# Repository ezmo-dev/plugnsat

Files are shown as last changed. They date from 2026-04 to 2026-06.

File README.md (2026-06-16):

# PlugNSat

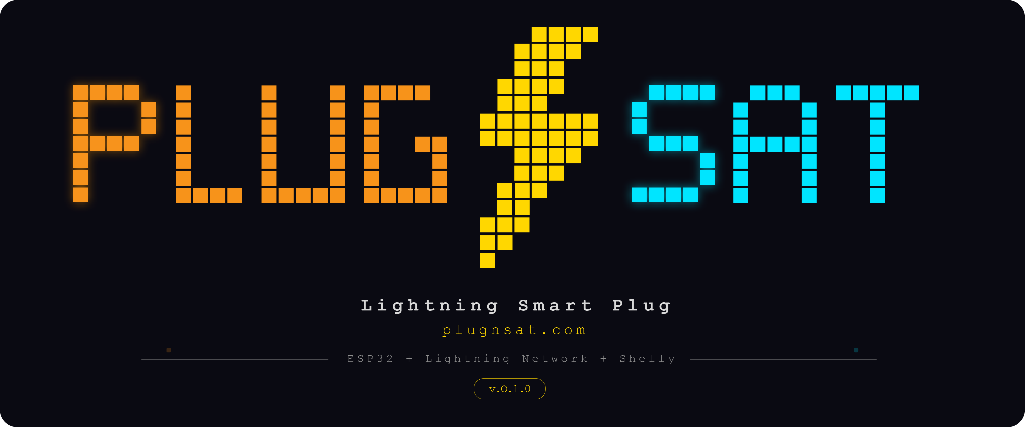
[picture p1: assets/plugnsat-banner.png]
cover

An open-source Lightning Smart Plug Controller. Turn any device into a Bitcoin-powered machine!

PlugNSat is an ESP32-based controller that displays a Lightning invoice QR code on screen.
When a customer pays, it triggers a CE-certified Shelly smart plug to power on any connected device (5V, 12V, 220V...) for a configurable duration and price.
Supports BTCPay Server (self-hosted) and Blink (hosted wallet) as Lightning backends.

Connect to WiFi, set your price in sats, and go!
No modification to the target device needed.

Built for Bitcoin hubs, conferences, stores, coworking spaces, companies, meetups, events, and more.

## How it works
```
[QR on screen] --> [Customer scans] --> [Pays Lightning] --> [Shelly ON] --> [New QR]
     ^                                                                          |
     |__________________________________________________________________________|
                              (automatic loop)
```

The QR code is always displayed. No button press needed to start a payment.
QR auto-refreshes every 4m45s before the 5-minute invoice expiry.

## Hardware

| Part | Price | Link |
|---|---|---|
| LilyGO T-Display S3 | ~20 EUR | [amazon.fr](https://www.amazon.fr/dp/B0BX8Q2MJP) |
| Shelly Plug S Gen3 | ~26 EUR | [amazon.fr](https://www.amazon.fr/dp/B0DJFQXTY2) |

## Arduino IDE Setup

1. Install [Arduino IDE 2.x](https://www.arduino.cc/en/software)
2. Add ESP32 boards: File > Preferences > Board Manager URLs:
   `https://raw.githubusercontent.com/espressif/arduino-esp32/gh-pages/package_esp32_index.json`
3. Install "esp32" in Board Manager
4. Board: ESP32S3 Dev Module
5. USB CDC On Boot: Enabled
6. Flash Size: 16MB
7. Partition Scheme: Minimal SPIFFS (1.9MB APP with OTA/128KB SPIFFS)

### Libraries (Sketch > Include Library > Manage Libraries)

- **TFT_eSPI** by Bodmer (+ configure User_Setup_Select.h for T-Display S3)
  - Line 27: Comment `#include <User_Setup.h>` (add `//` in front)
  - Line 133: Uncomment `#include <User_Setups/Setup206_LilyGo_T_Display_S3.h>` (remove `//`)
- **ArduinoJson** by Benoit Blanchon
- **QRCode** by Richard Moore

## Setup

### 1. Prepare the Shelly Plug

1. Download the **Shelly app** ([iOS](https://apps.apple.com/app/shelly-cloud/id1147164547) / [Android](https://play.google.com/store/apps/details?id=cloud.shelly.smartcontrol))
2. Plug the Shelly into a wall outlet
3. Open the app and follow the instructions to add the device to your WiFi network
4. Once connected, open the plug settings and, under Input/Output settings, configure the Shelly to turn OFF when it has power (so the connected device stays off until a payment is received)

> The Shelly must be on the same WiFi network that PlugNSat will connect to.

### 2. Flash the firmware (DIY only)

> Skip this step if you bought a pre-assembled PlugNSat.

1. Connect the LilyGO T-Display S3 to your computer via USB-C
2. Open Arduino IDE, select the board and settings (see [Arduino IDE Setup](#arduino-ide-setup) above)
3. Upload the firmware
4. The device shows the "PlugNSat Setup" screen

### 3. Configure PlugNSat

1. Power on the PlugNSat via USB-C
2. On your phone, connect to WiFi: `PlugNSat-Setup` (password: `plugnsat21`)
3. Open `http://192.168.4.1` in your browser
4. Enter your WiFi credentials (same network as the Shelly)
5. Choose your Lightning backend (BTCPay Server or Blink) and fill in the corresponding credentials
6. Click **Scan network** to auto-discover your Shelly, or type its hostname/IP manually
7. Set your price in sats, activation duration in seconds, optionally a 4-digit PIN to protect these settings on the device, and optionally a portal password to protect this web page (username: admin)
8. Click **Save and restart**
9. The device connects to WiFi and the QR code appears. You're live!

## Buttons

| Button | Short press | Long press (3s) |
|---|---|---|
| BTN1 (left) | Settings menu / Navigate | Enter AP setup mode |
| BTN2 (right) | Force QR refresh / Confirm | - |

## Firmware Updates

PlugNSat supports over-the-air updates. Two ways to update:

- **Auto-update on boot** (opt-in): enable it in the web portal and the device checks GitHub Releases at every boot, then installs new versions automatically.
- **One-click update**: open `http://plugnsat.local`, click **Check for updates** in the Firmware update section, then **Install update** if a new version is available.

All firmware is RSA-signed. The device verifies the signature before flashing and refuses unsigned or tampered files. If an update fails to boot, the device automatically rolls back to the previous version within 60 seconds.

### Settings menu

Press BTN1 from the QR screen to open the Settings menu.

| Option | Description |
|---|---|
| Device Info | WiFi, IP, RSSI, Shelly host, price, duration, payments, uptime |
| Brightness | Adjust screen brightness (BTN1 decreases, BTN2 increases) |
| Price | Change price in sats (BTN1 decreases, BTN2 increases) |
| Duration | Change activation duration in seconds (BTN1 decreases, BTN2 increases) |
| Turn OFF | Battery model only. Puts the device into deep sleep. Wake with BTN1 or by connecting USB power. |

Price and Duration can be protected with a 4-digit PIN, configurable in the web portal. If a PIN is set, it must be entered before accessing these settings.

Navigation: BTN1 moves the cursor, BTN2 selects. All screens return to the QR code automatically after 6 seconds of inactivity. Changes to Brightness, Price, and Duration are saved automatically on exit. On the Device Info screen, press any button to return to the QR code.

## Files
```
plugnsat.ino   Main sketch, state machine, WiFi, buttons
config.h       Constants, colors, config struct
display.h      All screen rendering (splash, QR, paid, error, info, settings, brightness, AP)
btcpay.h       BTCPay Server API (create invoice, check status)
blink.h        Blink wallet GraphQL API (create invoice, check status)
backend.h      Lightning backend abstraction layer (BTCPay Server, Blink)
shelly.h       Shelly local HTTP API (switch on/off, status)
webportal.h    Web config page (HTML/CSS/JS served by ESP32)
qrcode.h       QR code generation library header (by Richard Moore)
qrcode.c       QR code generation library source
ota.h          OTA system: rollback guard, RSA signature verification, GitHub update check and download
```

All files go in the same folder. Arduino IDE compiles them together.

## Edge Cases Handled

- WiFi disconnects > auto reconnect, QR regenerated
- Backend unreachable > retry 3x, then error screen, auto-retry 10s
- Invoice expires > new QR generated silently
- Shelly offline during payment > "Shelly not found" warning screen > auto-retry every 10s > when Shelly comes back online: paid screen with full countdown + activation command sent with full duration > payment is confirmed regardless of Shelly status
- Shelly hostname (mDNS .local) supported to avoid DHCP IP changes
- "Scan network" button in the web portal auto-discovers Shelly devices via mDNS (no IP needed)
- 60+ consecutive poll errors (5 min) > ESP32 restarts itself
- Long press BTN1 from any screen > AP setup mode

## License

MIT © 2026 - [ezmo-dev](https://github.com/ezmo-dev) (PlugNSat)

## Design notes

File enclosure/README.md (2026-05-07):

# Enclosure

3D printed case for the LilyGO T-Display S3 (version without header pins).

## Current model

- **Type**: USB-powered, no battery, no mount
- **Fits**: LilyGO T-Display S3 (170x20x8mm PCB)
- **Buttons**: accessible from outside
- **USB-C**: open slot at the bottom

## Print settings

- **Filament**: PLA or PETG
- **Layer height**: 0.2mm
- **Infill**: 15%
- **Supports**: no
- **Estimated time**: ~3h05

## Files

| File | Description |
|---|---|
| `stl/plugnsat-case_top.stl` | Top shell |
| `stl/plugnsat-case_bottom.stl` | Bottom shell |

## Planned variants

- [ ] Integrated LiPo battery version
- [ ] Wall mount
- [ ] Desk stand (angled for QR scanning)

## Notes

STL files are print-ready, no scaling needed.
Printing on a Dagoma DiscoEasy200

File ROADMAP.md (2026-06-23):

### v0.1 — Released
- [x] Basic prototype: LNURL QR, BTCPay polling, Shelly activation
- [x] Web portal configuration
- [x] Auto QR refresh before invoice expiry
- [x] Simulate payment button for testing
- [x] mDNS autodiscovery for Shelly devices
- [x] Splash screen with logo and branding
- [x] Color theme and screen brightness adjustments
- [x] Adjust price and duration from device buttons (PIN-protected)
- [x] First 3D print case
- [x] Web portal UI redesign (light theme, step-based layout)
- [x] UI polish: paid screen, error screen, info screen, settings screen
- [x] Better error messages and info indicators on all screens
- [x] Info tooltips on web portal fields
- [x] QR display modes: Show name/price toggles on QR screen (configurable via web portal)
- [x] First test video
- [x] Documentation structure: create outline with all major sections
- [x] README v1 on GitHub
- [x] Full code cleanup before moving forward

### v0.2 — Blink integration, OTA, and enclosures (current)
- [x] Blink wallet API integration
- [x] Backend choice on web portal: BTCPay or Blink
- [x] Web portal adapts fields based on backend choice
- [x] Update info indicators on web portal for both backends
- [x] Fix: infinite paid/activation loop after payment timer expires
- [x] Add descriptive memo to Blink invoices (device name + amount)
- [x] Merge Lightning Backend selector and credentials into a single configuration step
- [x] Add collapsible accordion sections to configuration page with chevron, summary line, and state persistence
- [x] Rewrite all configuration page tooltips for clarity
- [x] OTA Phase 1: partition scheme with two OTA slots, flash and reboot on the other slot, automatic rollback
- [x] OTA Phase 2: local Web OTA, upload a .bin from the portal (protected by portal password)
- [x] OTA Phase 3: firmware signing, RSA key pair, signature verified before any flash
- [x] OTA Phase 4: version check via GitHub Releases API, TLS validation with embedded root CA
- [x] OTA Phase 5: download and flash signed .bin from GitHub, opt-in via portal button
- [x] OTA Phase 6: controlled deployment, release delay and staged rollout, optional auto-update on boot
- [x] Research and select the right LiPo battery model (capacity, connector, dimensions for enclosure)
- [x] "Check for updates" button in web portal
- [x] Auto-update option on boot
- [x] Battery-powered prototype (LiPo integration with T-Display S3)
  - [x] GPIO15 power-enable for battery operation (screen on without USB)
  - [x] VBAT reading on GPIO4 with onboard divider, factory eFuse + 1.017 calibration
  - [x] Battery model flag (isBattery) in config + web portal toggle, persisted
- [x] Power management: sleep mode, low battery indicator on screen
  - [x] Manual Turn OFF in settings menu (deep sleep, wake on BTN_1 or USB)
  - [x] Software low-voltage cutoff at 3100mV (confirmed over consecutive reads)
  - [x] Low battery warning: blinking crossed-out icon, bottom-right of main screen
  - [x] RTC pull-up on wake pin to prevent immediate wake
- [x] Battery level indicator on screen and web portal
  - [x] Device Info: battery icon, voltage (X.XX/4.20V), percentage (LiPo curve)
  - [x] Charging icon when voltage trend is rising
- [x] Battery UI polish: refine design of all battery-related screen elements
- [ ] Enclosure prototypes (USB and battery): desk stand, magnetic mount, wall mount
- [ ] Test prints for each enclosure
- [x] General V0.2 audit: review all new features for correctness and consistency
- [x] Security audit: review all new features (portal auth, XSS, input validation)
- [ ] Finish documentation: User Manual, Web Portal Reference, Troubleshooting (Quick Start done; needed for landing page)

### v0.3 — Landing page and USB beta testing
- [ ] Finalize USB and battery enclosures and publish STL files on GitHub
- [ ] UI improvements on screen: price and device name alongside QR, WiFi signal indicator, battery level
- [ ] Full design coherence review: screens, web portal, enclosures, docs
- [ ] Landing page v1 on plugnsat.com (USB + battery)
- [ ] Product photos for landing page: device, enclosures, screens, setup flow
- [ ] Product video for landing page
- [ ] Quick-start guide (printed in box)
- [ ] Troubleshooting page
- [ ] Beta testing USB and battery models: send units to trusted people
- [ ] Collect feedback on setup, documentation, enclosure, daily use
- [ ] Code cleanup

### v0.4 — Product finalization and packaging
- [ ] Fix issues reported by beta testers
- [ ] Finalize battery enclosures: desk stand, magnetic mount, wall mount
- [ ] Packaging design: box, insert, printed quick-start guide, sticker
- [ ] Update documentation and landing page with beta feedback
- [ ] Product photos and video for USB and battery models

### v0.5 — Pre-launch and production ready
- [ ] Market study: target segments, pricing per model, competitors
- [ ] Pricing strategy finalized: USB, battery (kit vs pre-assembled)
- [ ] Sales channels defined: plugnsat.com, conferences, resellers, partner shops
- [ ] Landing page updated with final pricing and buy CTAs
- [ ] Collect testimonials from beta testers for landing page
- [ ] Full documentation site (docs.plugnsat.com)
- [ ] CE compliance documentation package for resellers
- [ ] Firmware changelog page on plugnsat.com
- [ ] Packaging production ready
- [ ] Stable, battle-tested product (USB and battery shipping reliably)

### v0.6 — Community sharing
- [ ] Share on Bitcoin communities: Twitter, Nostr, Telegram groups, forums
- [ ] Share on Reddit: r/bitcoin, r/lightningnetwork, r/esp32
- [ ] Present at local meetups
- [ ] Post on Plan B Network, Stacker News
- [ ] Collect feedback, testimonials, and early interest

### v1.0 — Sales and distribution
- [ ] Public sales on plugnsat.com: USB and battery (kit and pre-assembled)
- [ ] Battery model to resellers (desk stand, magnetic mount, wall mount)
- [ ] Contact Bitcoin shops and resellers
- [ ] Send demo units to potential partners
- [ ] Present at Bitcoin conferences
- [ ] Explore distribution partnerships (hubs, coworking chains, event organizers)

---
 
## Post-v1.0 (conditional on sales traction)
 
### NFC model
- [ ] NFC module integration (PN532 or similar)
- [ ] Tap-to-pay flow: NFC reads LNURL, wallet opens, pay
- [ ] NFC + QR dual mode on screen
- [ ] Enclosure prototypes for NFC model (antenna positioning)
- [ ] Finalize NFC enclosures and publish STL files
- [ ] Beta testing NFC model with trusted people
- [ ] Update documentation: NFC setup guide
- [ ] Update landing page with NFC model
- [ ] Product photos and video for NFC model
### Multi-device support
- [ ] New web portal section: device manager with "+" button to add PlugNSat units
- [ ] Per-device configuration: name, price, duration, Shelly host
- [ ] Device list view with status (online/offline, last payment, uptime)
- [ ] Edit and remove devices from the portal
- [ ] Multi-device firmware support (one BTCPay store, multiple devices)
- [ ] Multi-device documentation
- [ ] Beta testing multi-device with hub managers and coworking spaces
### Future ideas
- [ ] Sub-domain dashboard per client (client.plugnsat.com)
- [ ] Usage statistics and payment history
- [ ] Multiple Shelly devices per controller
- [ ] Multi-language support on web portal and screen
- [ ] Fiat price display (sats + EUR/USD equivalent)
- [ ] Receipt/proof of payment via email or NFC
- [ ] Referral program for existing buyers
- [ ] White-label option (custom branding per client)
- [ ] Optional OLED/AMOLED screen version for outdoor use
- [ ] Wall-flush Shelly install behind drywall
### Product lineup
- **PlugNSat USB** - Base model (USB-C powered, kit or pre-assembled) — plugnsat.com only
- **PlugNSat Battery** - Portable model (LiPo rechargeable, kit or pre-assembled) — plugnsat.com and resellers
- **PlugNSat NFC** - Premium model (QR + tap-to-pay), post-v1.0 if sales follow
- **Enclosures** - Desk stand, magnetic mount, wall mount
- **Accessories** - Extra Shelly Plug S Gen3, replacement USB-C cables, sticker pack
- **Free resources** - STL files on GitHub, online documentation, open-source firmware

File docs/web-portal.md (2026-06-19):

# Web Portal Reference

The web portal is the configuration interface served by the PlugNSat itself. It runs directly on the ESP32 and is accessible from any browser on the same network.

## How to access the web portal

There are two ways to reach the web portal depending on the device's current state:

**During first setup (AP mode):**

1. Connect your phone to WiFi: `PlugNSat-Setup` (password: `plugnsat21`)
2. Open `http://192.168.4.1` in your browser

**After setup (normal mode):**

1. Connect to the same WiFi network as the PlugNSat
2. Find the device's IP address (shown on the Device Info screen: BTN1 from QR > Device Info)
3. Open `http://<device-ip>` in your browser, or use `http://plugnsat.local` (mDNS)

> The web portal works on any modern browser: Safari, Chrome, Firefox, on both mobile and desktop. No app needed.

> In AP mode the portal is never password-protected, so you can never lock yourself out during setup. A Web Access Password (see Step 5) only applies in normal mode on your WiFi.

> **AP mode is a configuration and recovery mode, not an operating mode.** Anyone who can connect to the `PlugNSat-Setup` network (password: `plugnsat21`) has unrestricted access to the portal. Once you have entered your WiFi credentials and pressed Save, the device switches to normal mode where the Web Access Password is enforced. Do not leave the device in AP mode during normal operation.

---

## Configuration fields

The portal is organized in 5 steps. All fields are saved at once when you press **Save and restart**. Each step can be collapsed or expanded by tapping its title; the collapsed state is remembered in your browser.

### Step 1: WiFi

| Field | Description | Example |
|---|---|---|
| **SSID** | Your WiFi network name (2.4 GHz). The Shelly must be on the same network. | `MyHomeWiFi` |
| **Password** | Your WiFi password. | `********` |

> The Shelly Plug S Gen3 only supports 2.4 GHz networks. If your router broadcasts both 2.4 and 5 GHz under the same name, you may need to separate them or force the 2.4 GHz band.

> For security, saved passwords are never sent back to the browser. Existing values appear as `********`. Leave them untouched to keep the current password, or type a new one to replace it.

### Step 2: Lightning Backend

PlugNSat supports two Lightning backends. Select one from the **Backend** dropdown; the form shows only the fields for the selected backend.

| Backend | When to use |
|---|---|
| **BTCPay Server** | You run your own server. Full control, no middleman. |
| **Blink** | A ready-to-use wallet, no server needed. Sign up at `blink.sv`. |

#### BTCPay Server fields

| Field | Description | Example |
|---|---|---|
| **Server URL** | The full URL of your BTCPay Server instance. No trailing slash. | `https://btcpay.mydomain.com` |
| **API Key** | Your BTCPay Greenfield API key. Must have the correct permissions (see below). | `a1b2c3d4e5...` |
| **Store ID** | Your BTCPay Store ID. Found in Settings > General or in the URL. | `8HRcCq...HwPs` |

##### Required API key permissions

The API key must have exactly these three permissions enabled:

| Permission | Internal name | Why it's needed |
|---|---|---|
| Create invoices | `cancreateinvoice` | To generate Lightning invoices when a customer scans the QR |
| View invoices | `canviewinvoices` | To check if an invoice has been paid (polling) |
| Use Lightning node | `canuselightningnode` | To retrieve the LNURL from the invoice's payment methods |

To create a key: BTCPay Server > Account > Manage Account > API Keys > Generate Key > check the three permissions > Generate > copy immediately.

##### How it works technically

When a QR code needs to be generated, the PlugNSat:

1. Creates an invoice via `POST /api/v1/stores/{storeId}/invoices` with amount in BTC, payment methods `BTC-LN` and `BTC-LNURL`, and a 5-minute expiry
2. Fetches the payment methods via `GET /api/v1/stores/{storeId}/invoices/{id}/payment-methods`
3. Extracts the LNURL from the `BTC-LNURL` payment method's `paymentLink` field
4. Displays the LNURL as a QR code (much shorter than a BOLT11 invoice, which makes the QR simpler and easier to scan on the small LCD)
5. Polls the invoice status every 5 seconds via `GET /api/v1/stores/{storeId}/invoices/{id}` and checks for `Settled` or `Processing`

#### Blink fields

| Field | Description | Example |
|---|---|---|
| **API Key** | Your Blink API key. Generate one at `dashboard.blink.sv` under API Keys. | `blink_...` |
| **BTC Wallet ID** | Which wallet receives the sats. Found at `dashboard.blink.sv`. | `f79a...` |

> Blink uses the GraphQL API at `https://api.blink.sv/graphql` (fixed endpoint, no server URL to enter). It returns a BOLT11 invoice rather than an LNURL, so the QR code is longer than with BTCPay but still scannable easily.

### Step 3: Shelly Plug

| Field | Description | Example |
|---|---|---|
| **Shelly hostname or IP** | The address of your Shelly on the local network. Can be an IP or an mDNS hostname. | `shellyplugsg3-9070694c2cd4.local` |

> Make sure the Shelly is plugged in, on the same WiFi, and set to **Off** as its default power-on state.

#### Scan network

Click **Scan network** to auto-discover Shelly devices on the local network via mDNS. The PlugNSat queries `_http._tcp` services and keeps the ones whose hostname starts with `shelly`. Matches appear in a dropdown for easy selection.

<p>
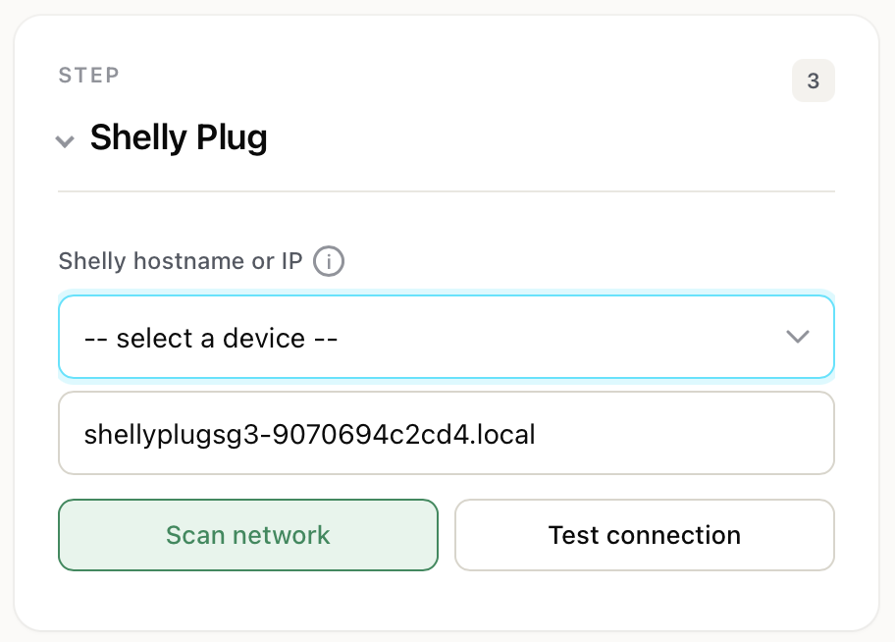
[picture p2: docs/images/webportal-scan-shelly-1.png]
    
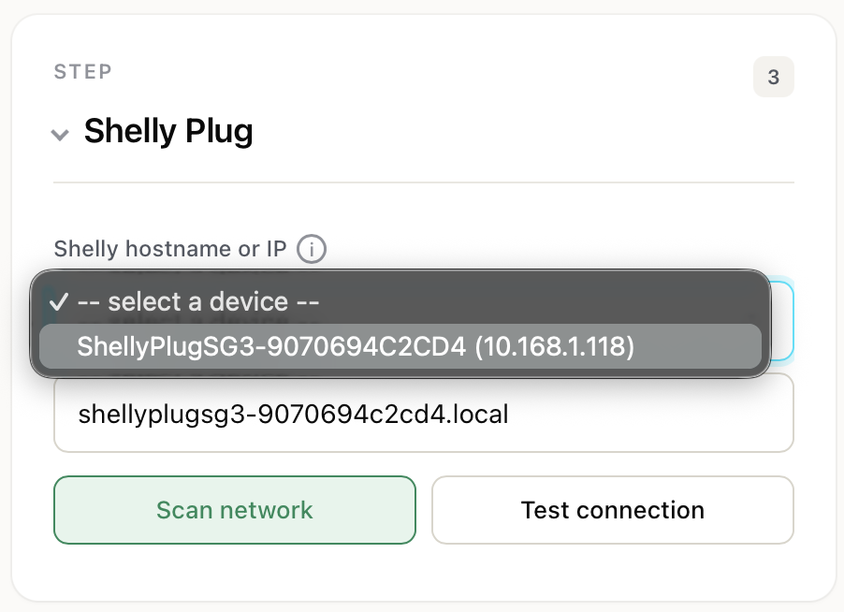
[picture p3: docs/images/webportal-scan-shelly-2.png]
    
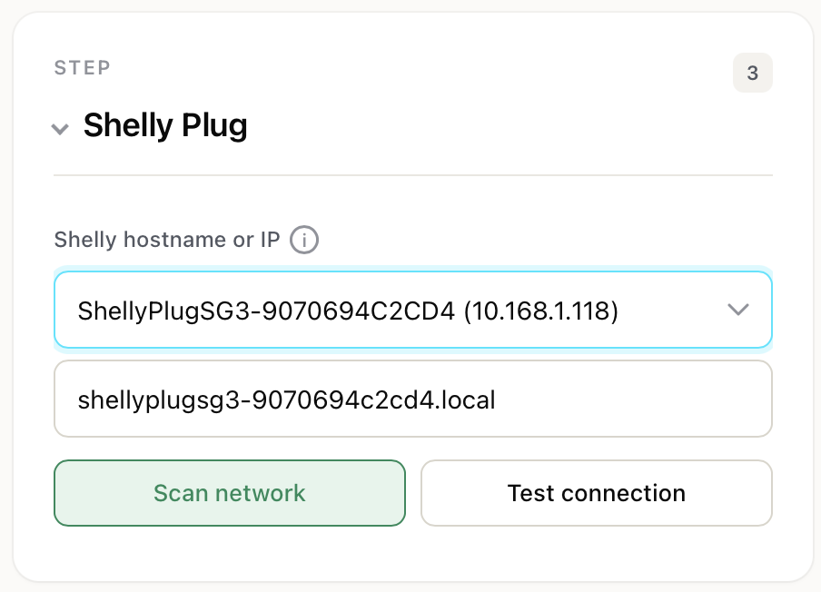
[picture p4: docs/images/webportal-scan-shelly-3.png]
    
<p>

> **Tip:** Use the mDNS hostname (`.local`) instead of the IP address. IP addresses can change if your router assigns a new one via DHCP. The mDNS hostname stays the same.

#### Test connection

Click **Test connection** to verify the PlugNSat can reach the Shelly. It sends an HTTP request to the Shelly's status endpoint (`/rpc/Switch.GetStatus?id=0`). If successful, you see a green confirmation with the current power draw in watts.

<p>
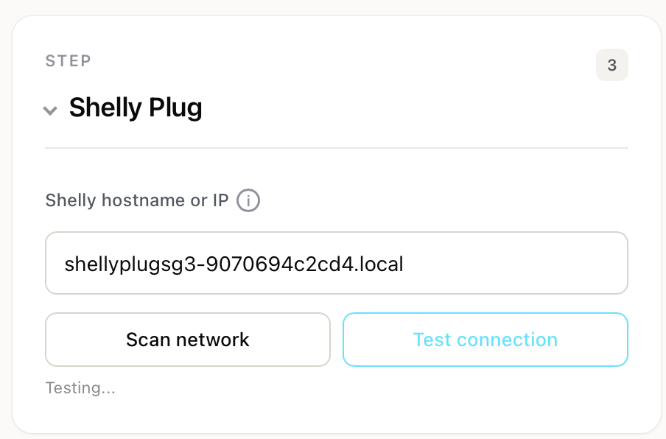
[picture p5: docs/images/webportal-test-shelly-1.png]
    
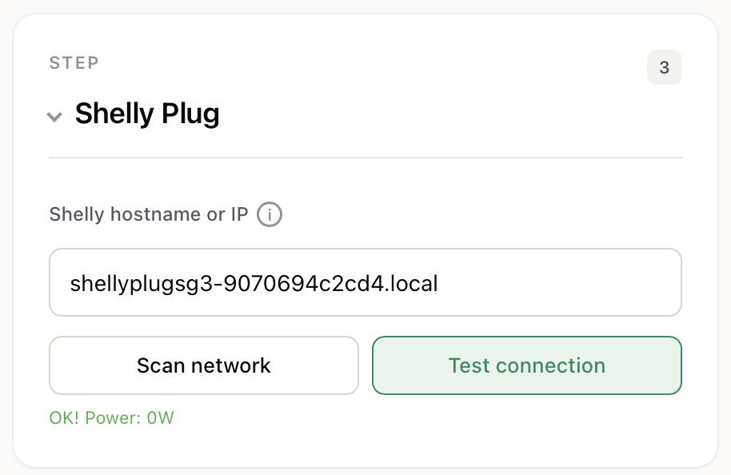
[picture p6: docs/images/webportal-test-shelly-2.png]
    
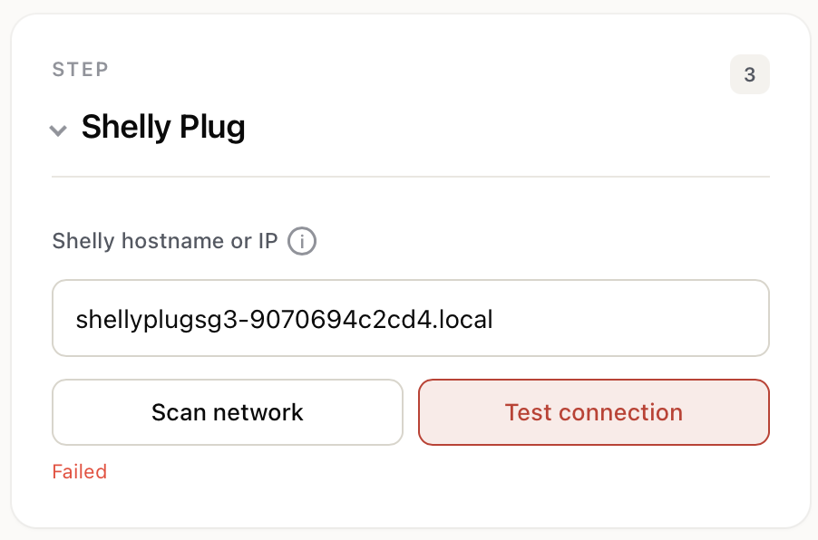
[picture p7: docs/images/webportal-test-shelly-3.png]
    
<p>

#### How the Shelly is controlled

The PlugNSat communicates with the Shelly via local HTTP API (Shelly Gen2+ RPC). No cloud, no internet, no firmware modification.

| Action | Endpoint |
|---|---|
| Turn on (with auto-off timer) | `GET /rpc/switch.set?id=0&on=true&toggle_after={seconds}` |
| Turn off | `GET /rpc/switch.set?id=0&on=false` |
| Check status | `GET /rpc/Switch.GetStatus?id=0` |

The `toggle_after` parameter tells the Shelly to turn itself off after the configured duration. This means even if the PlugNSat loses power or WiFi, the Shelly will still turn off on time.

### Step 4: Device settings

| Field | Description | Default | Range |
|---|---|---|---|
| **Name** | Display name for your PlugNSat. Shown on the info panel next to the QR if enabled. | `PlugNSat` | 1 to 40 characters (max 18 when "Show name" is on) |
| **Show name on QR screen** | Toggle. When on, the name appears next to the QR code. | Off | On/Off |
| **Price (satoshis)** | The amount a customer pays per activation. | `100` | 1 to 1,000,000 sats |
| **Duration (seconds)** | How long the Shelly stays on after payment. | `60` | 1 to 86400 (24h) |
| **Show price on QR screen** | Toggle. When on, the price in sats appears next to the QR code. | Off | On/Off |

> **Name length and QR layout:** If "Show name" is enabled, the QR code shifts to the left to make room for the info panel. Long names (more than 9 characters) wrap to two lines. With display enabled the portal enforces a maximum of 18 characters; with display off the limit is 40.

#### Simulate payment

Below the device fields you will find a **Simulate payment (free)** button. This triggers the Shelly for the configured duration without creating a real Lightning invoice or spending any sats.

<p>
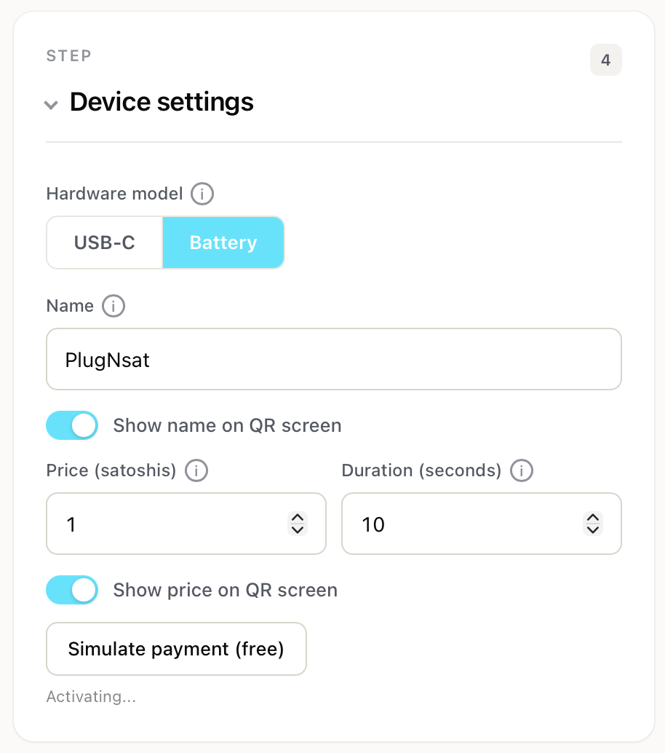
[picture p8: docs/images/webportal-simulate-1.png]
    
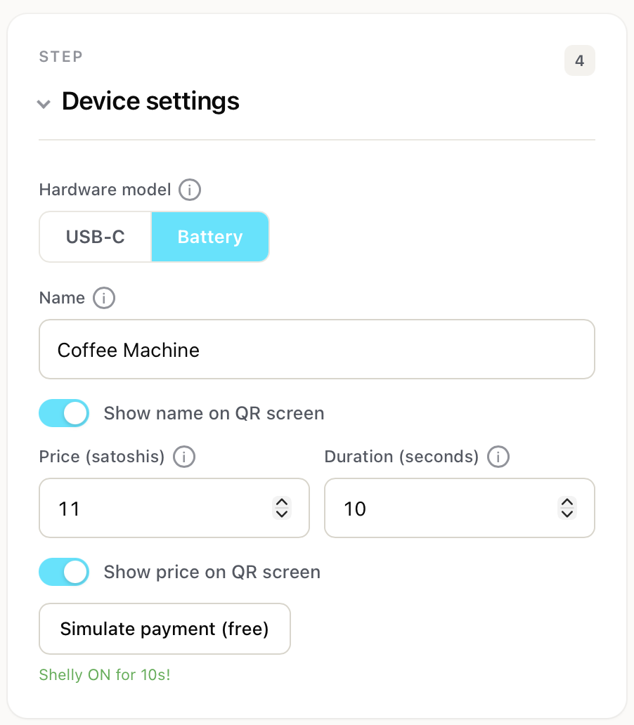
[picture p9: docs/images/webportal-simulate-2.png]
    
<p>

This is useful for:
- Testing the Shelly connection during setup
- Demoing the product without needing a Lightning wallet
- Verifying the device works end-to-end

### Step 5: Security

| Field | Description | Default | Range |
|---|---|---|---|
| **Device PIN** | Optional 4-digit code that protects Price and Duration on the device buttons. | Empty (disabled) | 4 digits or empty |
| **Web Access Password** | Optional password to protect this configuration page in normal mode. Login username is always `admin`. | Empty (disabled) | Any length or empty |

> The Device PIN prevents anyone near the PlugNSat from changing price and duration with the physical buttons. The Web Access Password prevents anyone on your WiFi from opening this page. The password is always disabled in setup (AP) mode so you cannot lock yourself out.

> **Credentials reminder:** When your browser prompts for a login in normal mode, enter **`admin`** as the username and your configured password. The username is fixed and cannot be changed.

---

## Firmware update

Below the **Save and restart** button is a Firmware update card. It shows the current firmware version and lets you keep the device up to date.

| Option | Behavior |
|---|---|
| **Auto-update on boot** | When enabled, the device checks GitHub Releases for a newer version every time it restarts and installs it automatically. Leave it off to stay in full control. |
| **Check for updates** | Manual check. Queries the GitHub Releases API over HTTPS and reports whether a newer version is available. Shown only when auto-update is off. |

Updates are verified with an RSA-SHA256 signature before flashing, so an unsigned or tampered firmware is refused.

---

## After saving

When you click **Save and restart**:

1. All settings are saved to the ESP32's non-volatile memory (NVS)
2. The device reboots
3. It connects to the configured WiFi
4. A new QR code is generated with the new settings

Settings persist across reboots and power losses. The only way to lose them is a firmware reflash or a factory reset.

---

## Accessing the portal in normal mode

After setup, the web portal remains accessible at the device's IP address or at `http://plugnsat.local`. You can change any setting at any time by visiting this page from your phone or laptop on the same network.

The IP address is displayed on the **Device Info** screen (BTN1 from QR > Device Info). You can also find it in your router's admin panel under connected devices, usually listed as "plugnsat" or "espressif".

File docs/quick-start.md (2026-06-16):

# Quick Start Guide

Get your PlugNSat up and running in under 10 minutes. This guide covers everything from opening the box to receiving your first Lightning payment.

> **Pre-assembled unit?** Skip straight to [Step 2: Set up the Shelly Plug](#step-2--set-up-the-shelly-plug). The firmware is already flashed.

## What's in the box

> **Two models:** The **battery model** runs on its internal battery or on USB-C power. The **USB-C-only model** is identical but has no battery, so it always stays plugged in. This guide applies to both; wherever it says "connect USB-C power", the battery model can also run unplugged.

Box contents
> *Image coming soon*

- 1x PlugNSat device (LilyGO T-Display S3, pre-flashed; battery model in the boxed version, USB-C-only model also available)
- 1x 3D-printed enclosure with 4 built-in magnets and 2 screw holes for wall mounting
- 1x desk stand (place it as-is, screw it, or stick it with double-sided tape)
- 1x Shelly Plug S Gen3 (CE-certified smart plug)
- 1x USB-C cable (1.5m, braided)
- 1x Quick-start card with QR code to this documentation

## Before you start

You will need:

- A WiFi network (2.4 GHz, the Shelly does not support 5 GHz)
- A smartphone to configure the Shelly and the PlugNSat
- A Lightning backend: **Blink wallet** (easy, no server needed) or **BTCPay Server** (self-hosted, advanced)
- A USB-C power source (phone charger, power bank, laptop USB port, anything)
- Something to power with the Shelly: a lamp, a coffee machine, a phone charger, anything with a plug

## Step 1 — Choose your Lightning backend

PlugNSat needs a Lightning backend to create invoices and detect payments. You have two options:

| | Blink | BTCPay Server |
|---|---|---|
| Difficulty | Easy (5 min) | Advanced (1+ hours if starting from scratch) |
| Cost | Free | Free (self-hosted) or ~5 EUR/month (hosted) |
| Requires | A Blink account | A BTCPay Server instance with Lightning |
| Custody | Blink holds your sats | You hold your keys |
| Best for | Getting started fast, demos, events | Permanent setups, sovereignty, businesses |

**Pick one and follow the matching section below.** You can always switch later from the web portal.

---

### Option A: Set up with Blink (recommended for beginners)

1. Download the **Blink wallet** ([iOS](https://apps.apple.com/app/blink-bitcoin-beach-wallet/id1531383905) / [Android](https://play.google.com/store/apps/details?id=com.galoyapp))
2. Create an account and verify your phone number
3. Go to **Settings > API Keys** in the Blink app or on [dashboard.blink.sv](https://dashboard.blink.sv)
4. Create a new API key and copy it

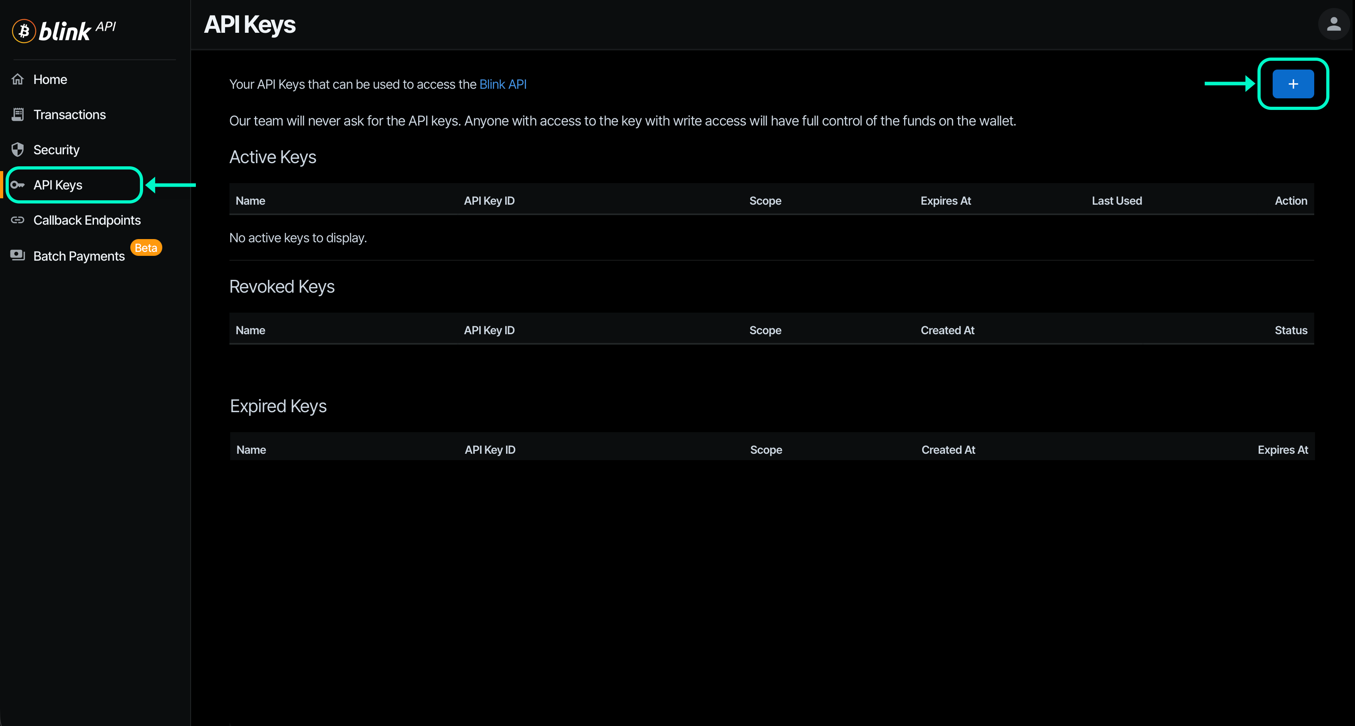
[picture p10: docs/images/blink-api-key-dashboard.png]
Blink API key Dashboard

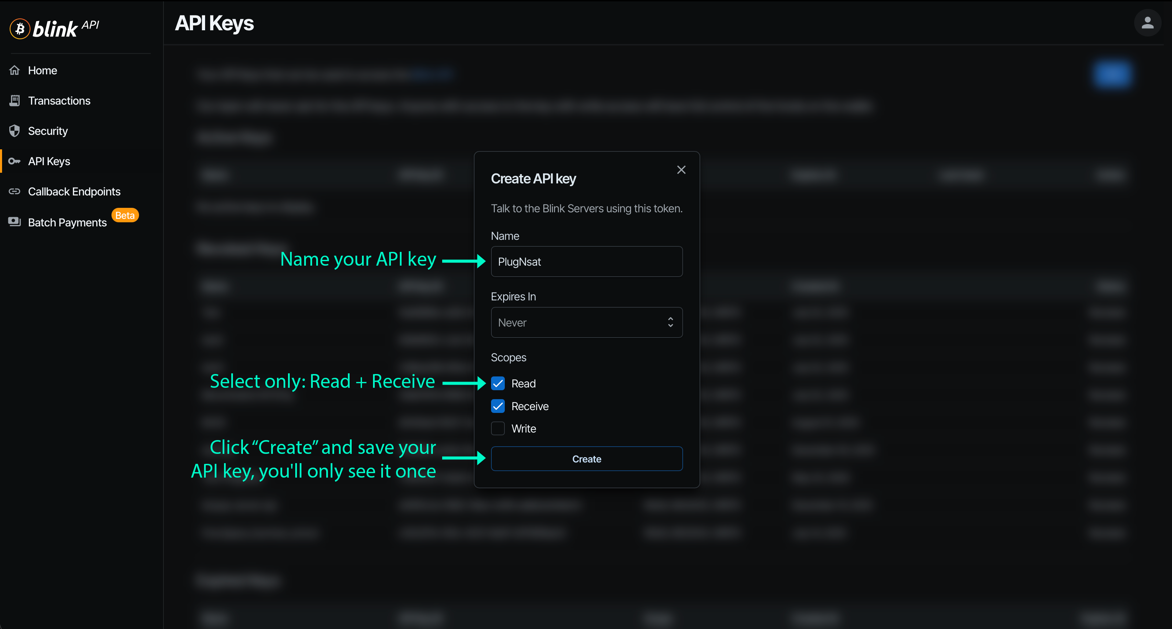
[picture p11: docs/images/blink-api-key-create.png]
Blink API key Creation


5. Save your API key in a secure location (password vault) and keep it handy for step 4
6. Keep your wallet ID in a safe place (such as a password manager) and have it handy for Step 4 as well

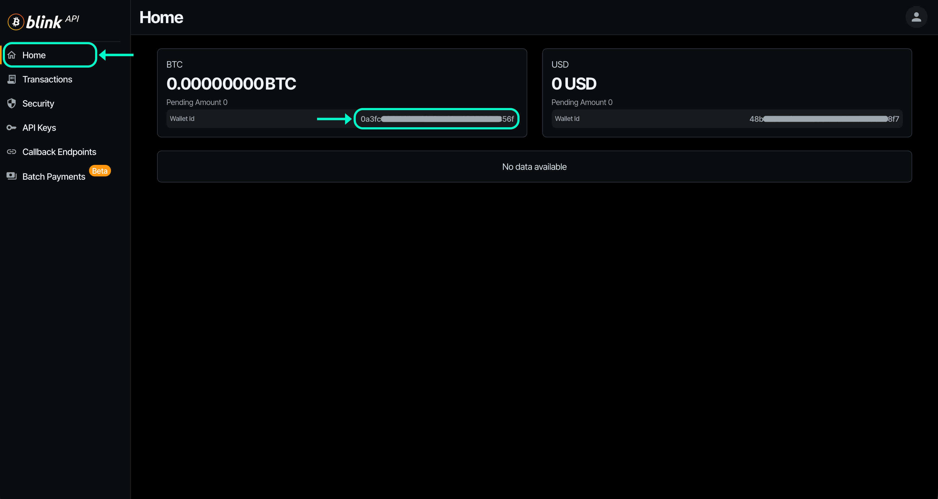
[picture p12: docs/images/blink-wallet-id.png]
Blink Wallet ID


---

### Option B: Set up with BTCPay Server

If you already have a BTCPay Server instance running with Lightning, you need three things:

1. **Server URL** (e.g. `https://btcpay.yourdomain.com`)
2. **Store ID**
3. **API Key** with the right permissions

#### Find your Store ID

Your Store ID is the long string visible in the URL when you open your store in BTCPay Server. You can also find it in **Settings > Store Settings**.

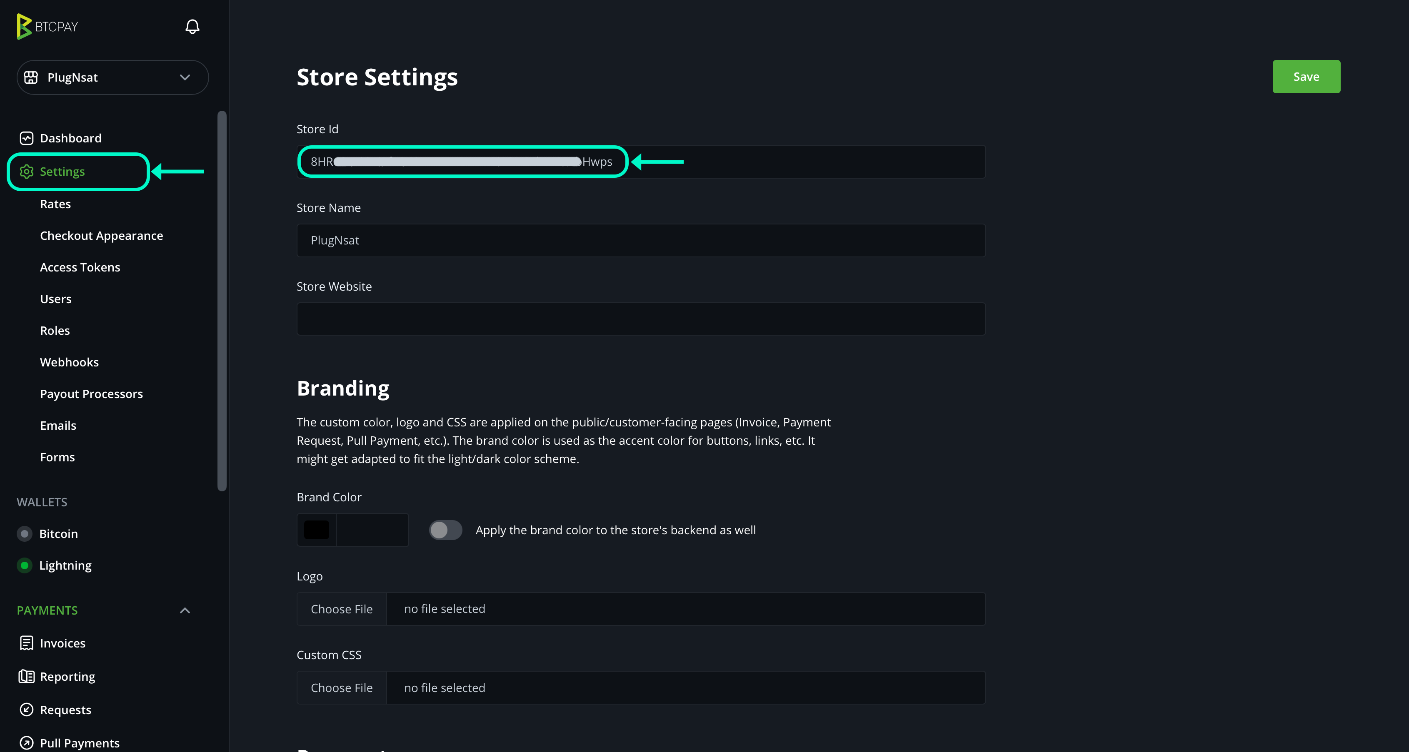
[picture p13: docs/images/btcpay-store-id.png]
BTCPay Store ID


#### Create an API Key

1. In BTCPay Server, go to **Account > Manage Account > API Keys**
2. Click **Generate Key**
3. Check exactly these permissions:
   - `cancreateinvoice` (Create invoices)
   - `canviewinvoices` (View invoices)
   - `canuselightningnode` (Use the Lightning node)
4. Click **Generate**
5. **Copy the key immediately.** It will not be shown again.

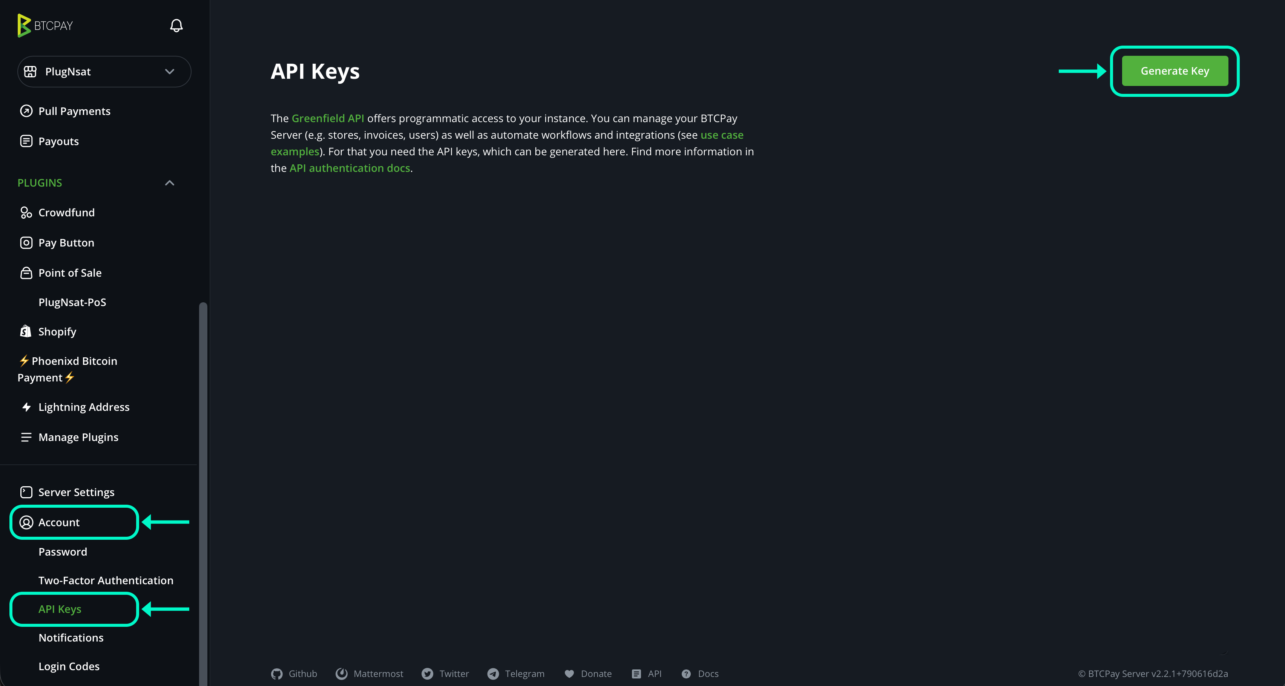
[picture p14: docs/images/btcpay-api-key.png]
BTCPay API Key

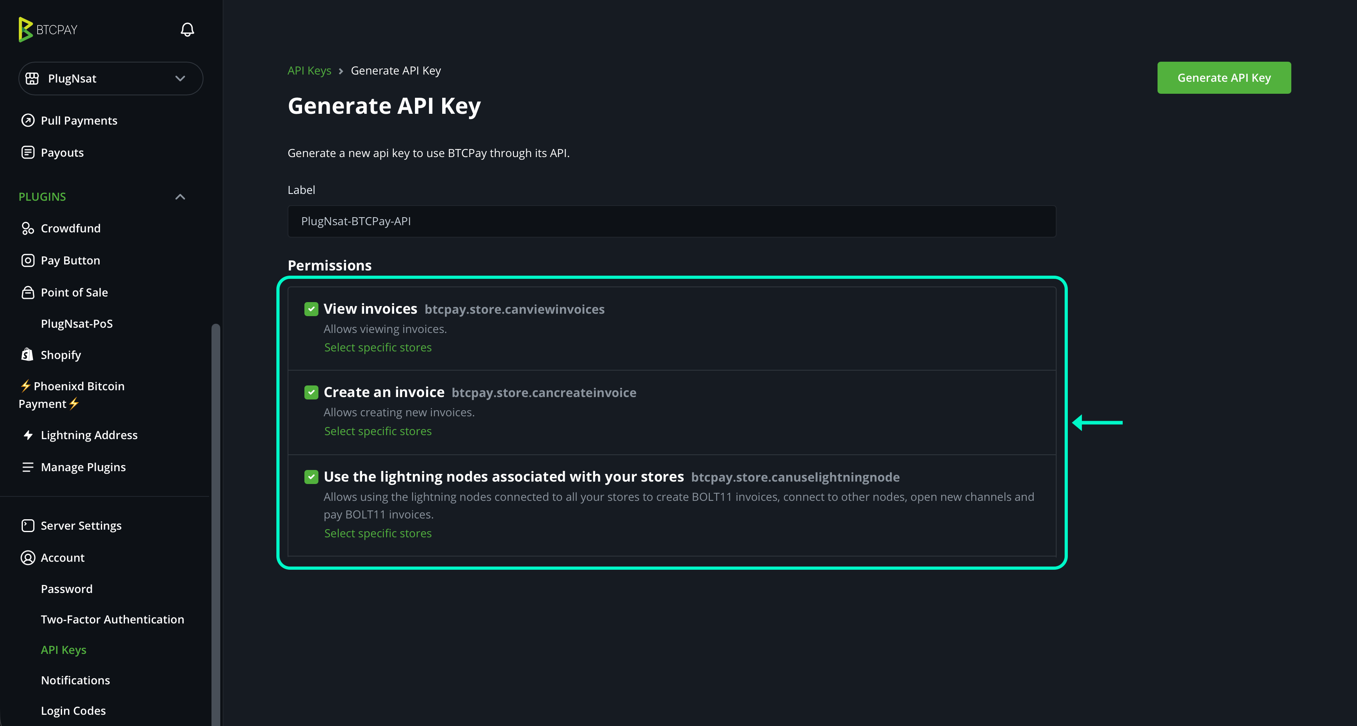
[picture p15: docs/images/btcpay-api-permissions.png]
BTCPay API permissions


> **Don't have a BTCPay Server yet?** You can set one up for free on your own server by following the [official deployment guide](https://docs.btcpayserver.org/Deployment/), or use a hosted solution like [LunaNode](https://launchbtcpay.lunanode.com/) or [Voltage](https://voltage.cloud/). You will also need a Lightning node connected (Phoenixd, LND, or CLN).

#### Make sure Lightning is working

In your BTCPay Server store, go to **Lightning > Settings** and make sure a Lightning node is connected and operational. You should see a green status indicator.

While you are here, go to **Lightning > Settings** and make sure LNURL is enabled. PlugNSat uses LNURL to generate compact QR codes that are easier to scan on the small screen.

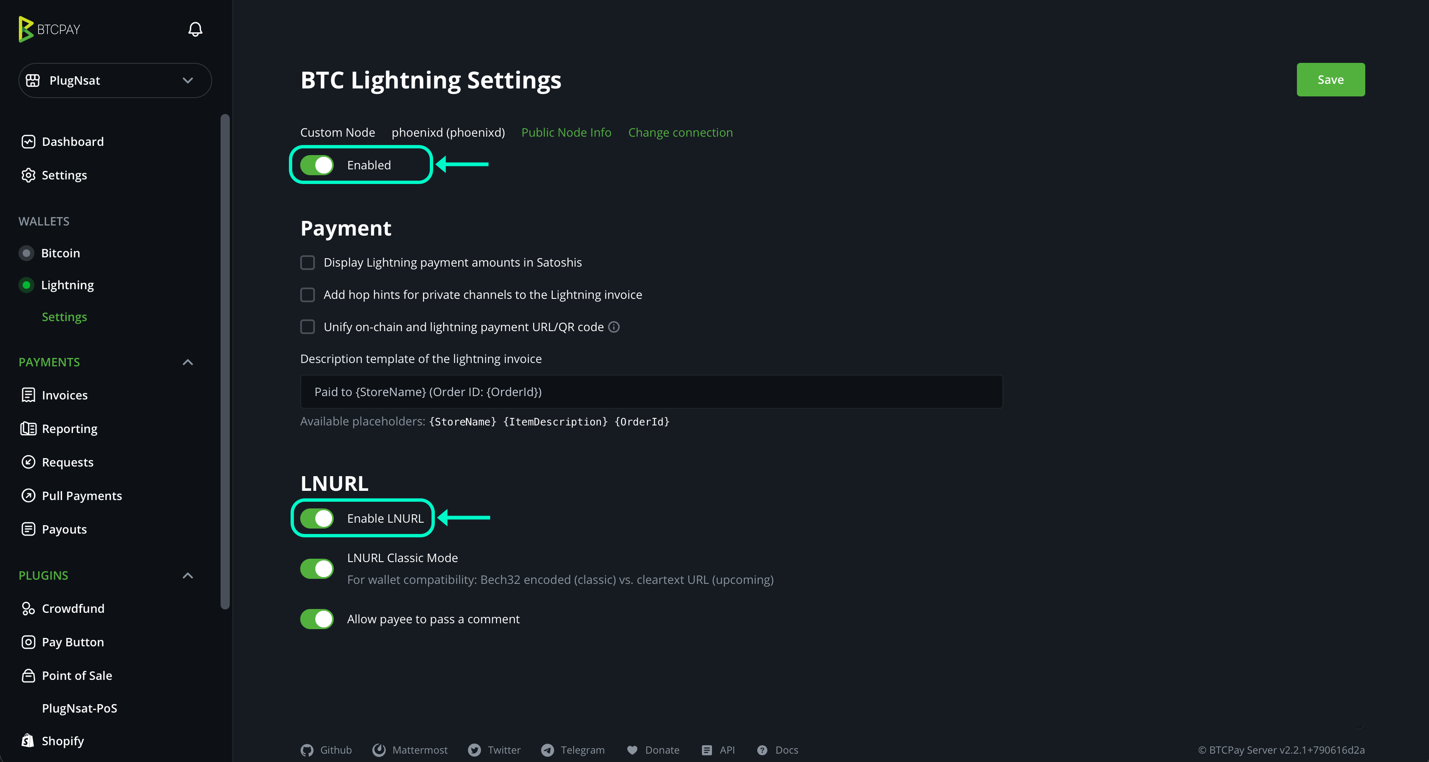
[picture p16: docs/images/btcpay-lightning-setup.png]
BTCPay Lightning setup


Keep the Server URL, Store ID, and API Key ready for Step 4.

---

## Step 2 — Set up the Shelly Plug
 
The Shelly Plug S Gen3 is the smart plug that PlugNSat controls. It handles the 220V switching safely, is CE-certified, and requires no modification.
 
> **Important:** The Shelly must be on the same Wi-Fi network as your PlugNSat. If you have a dual-band router, make sure both devices are on the 2.4 GHz band.
 
**Pairing the Shelly with the app**
 
1. Download the **Shelly app** ([iOS](https://apps.apple.com/app/shelly-cloud/id1147164547) / [Android](https://play.google.com/store/apps/details?id=cloud.shelly.smartcontrol))
2. Plug the Shelly into a wall outlet. It should flash blue.
3. Make sure your phone is connected to Wi-Fi and that Bluetooth is enabled.
4. Open the app and tap the blue "+" button at the bottom right. Select "Add via Bluetooth". Your Shelly Plug should be detected automatically.

<p align="center">
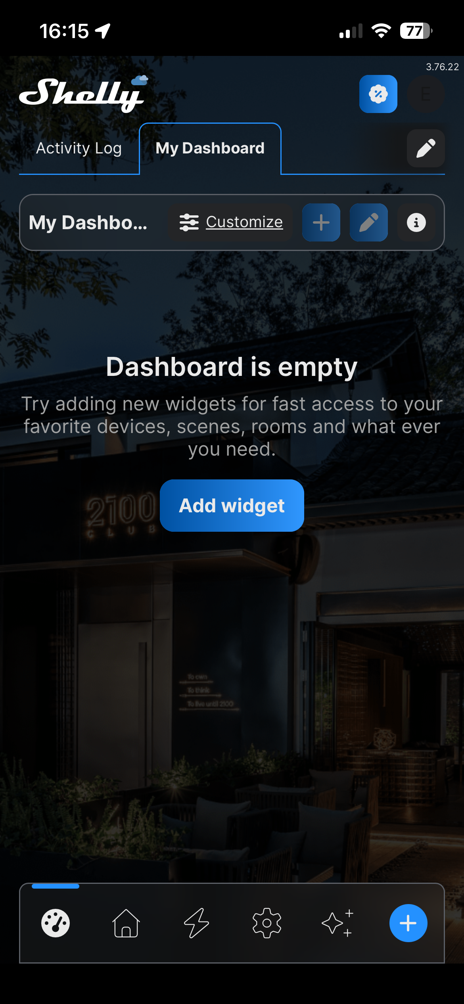
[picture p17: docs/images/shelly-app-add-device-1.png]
Shelly app home screen with the blue + button at the bottom right
  
  <span style="vertical-align: middle">&nbsp;&nbsp;→&nbsp;&nbsp;</span>
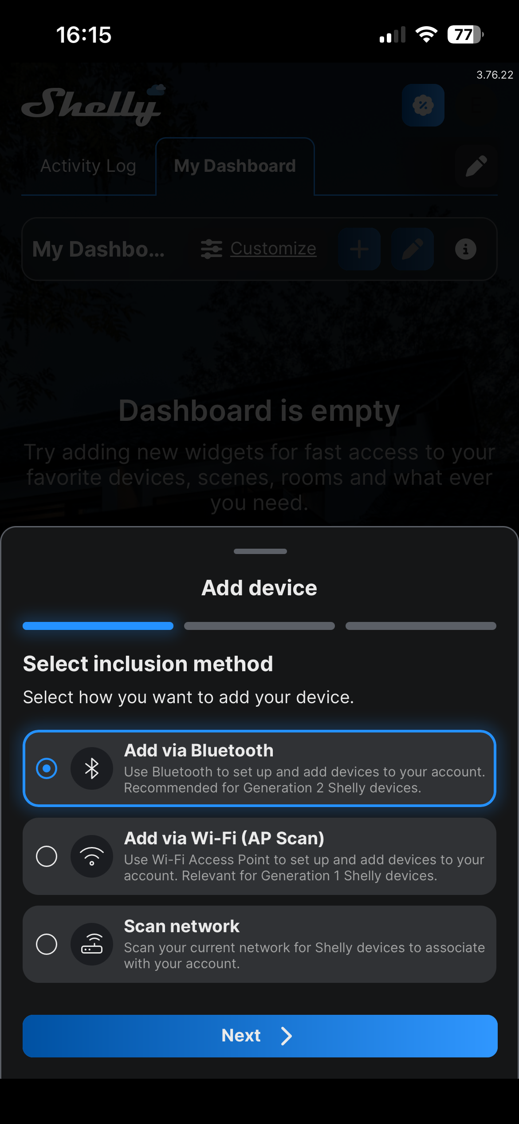
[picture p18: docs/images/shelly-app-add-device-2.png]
Add via Bluetooth option selected in the Shelly app
  
  <span style="vertical-align: middle">&nbsp;&nbsp;→&nbsp;&nbsp;</span>
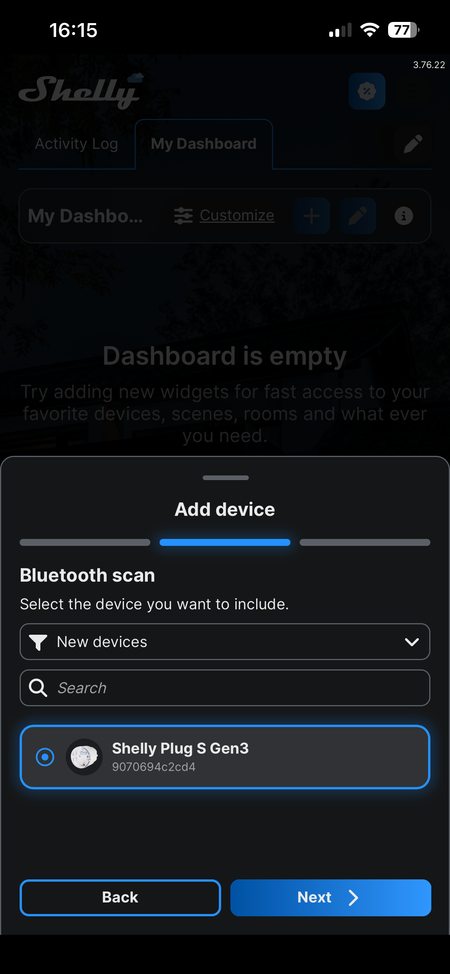
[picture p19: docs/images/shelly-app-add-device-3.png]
Shelly Plug detected automatically via Bluetooth
  
</p>

5. Confirm your Wi-Fi network is correct, then tap "Add device" and wait for the setup to finish.

<p align="center">
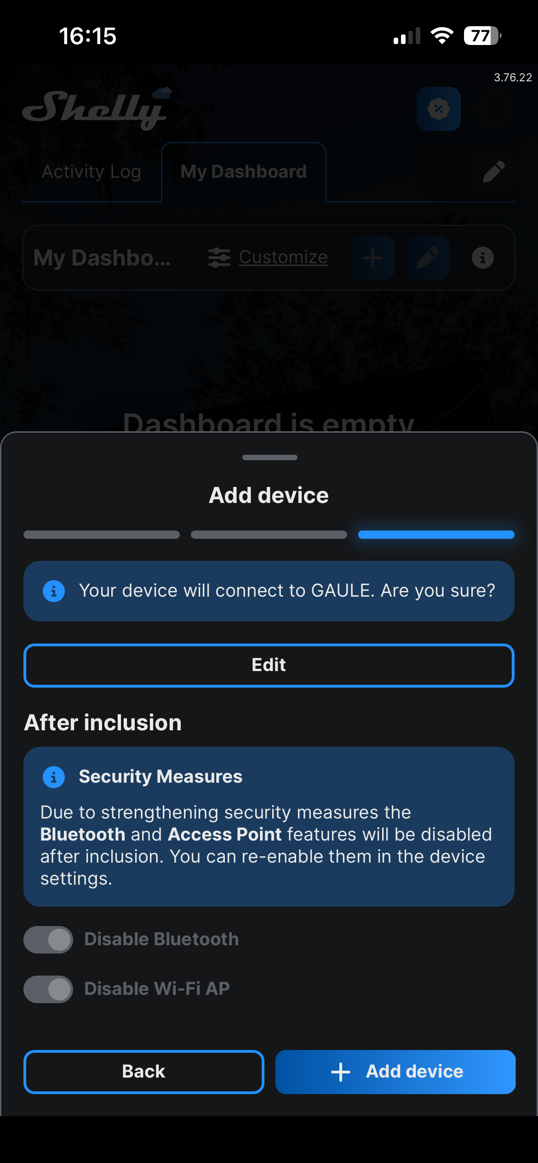
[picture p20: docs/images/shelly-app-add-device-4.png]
Wi-Fi network confirmation screen
  
  <span style="vertical-align: middle">&nbsp;&nbsp;→&nbsp;&nbsp;</span>
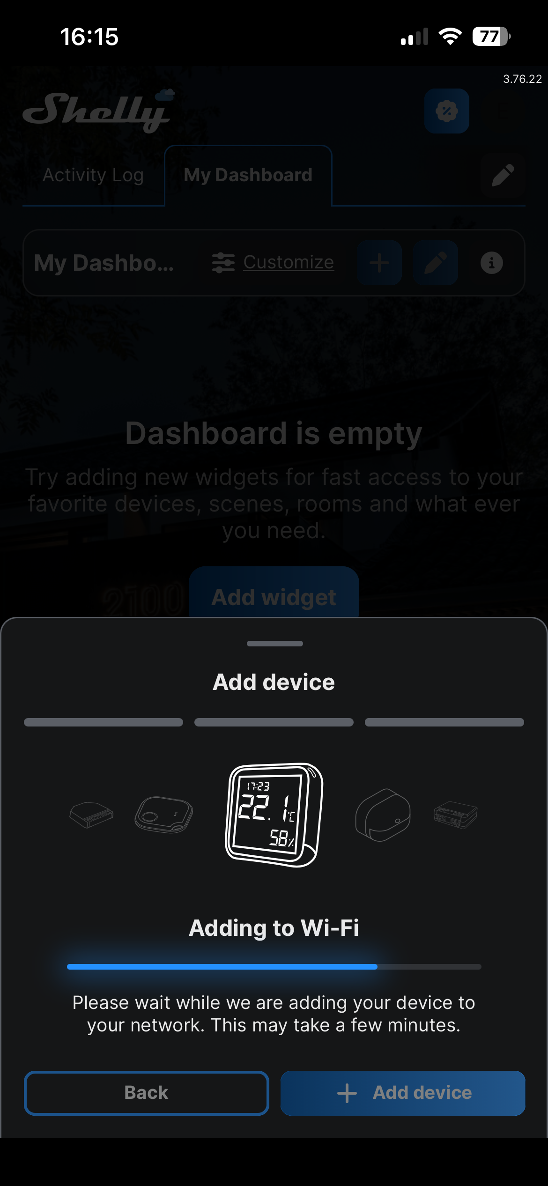
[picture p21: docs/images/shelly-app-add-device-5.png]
Add device button to start the installation
  
  <span style="vertical-align: middle">&nbsp;&nbsp;→&nbsp;&nbsp;</span>
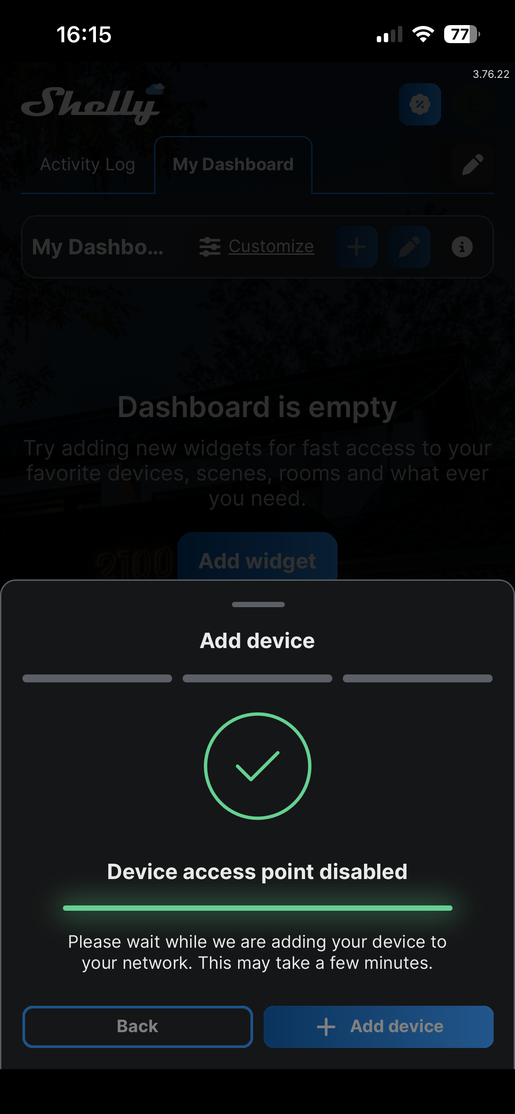
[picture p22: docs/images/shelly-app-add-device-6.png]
Installation in progress screen
  
</p>

6. Give your Shelly Plug a name so you can identify it if you have several.

<p align="center">
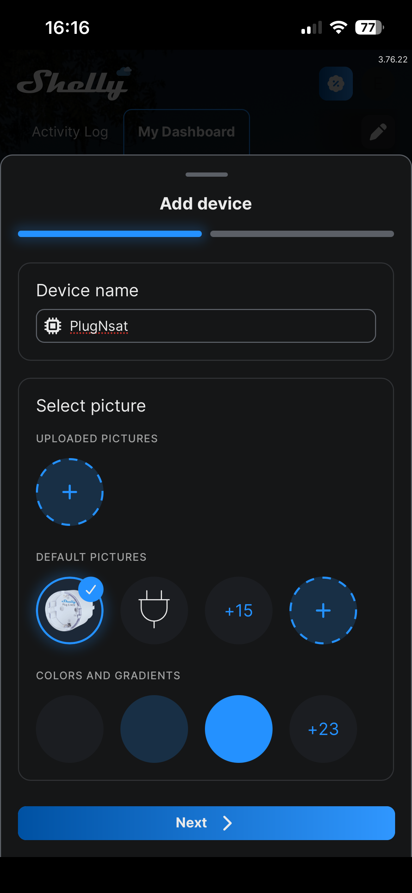
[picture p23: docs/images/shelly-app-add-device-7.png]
Device naming screen in the Shelly app
  
  <span style="vertical-align: middle">&nbsp;&nbsp;→&nbsp;&nbsp;</span>
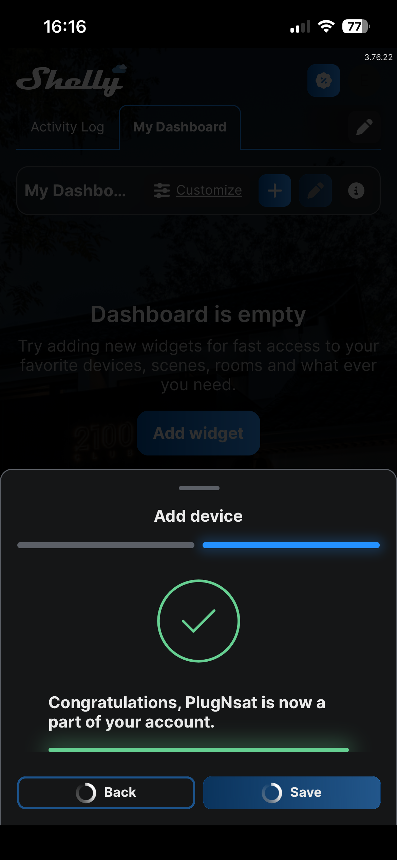
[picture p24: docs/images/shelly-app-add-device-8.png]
Shelly Plug successfully added and visible in the device list
  
</p>

**Configuring the initial state**
 
7. Go to the "All Devices" tab and tap your Shelly Plug. Scroll down to "Settings".

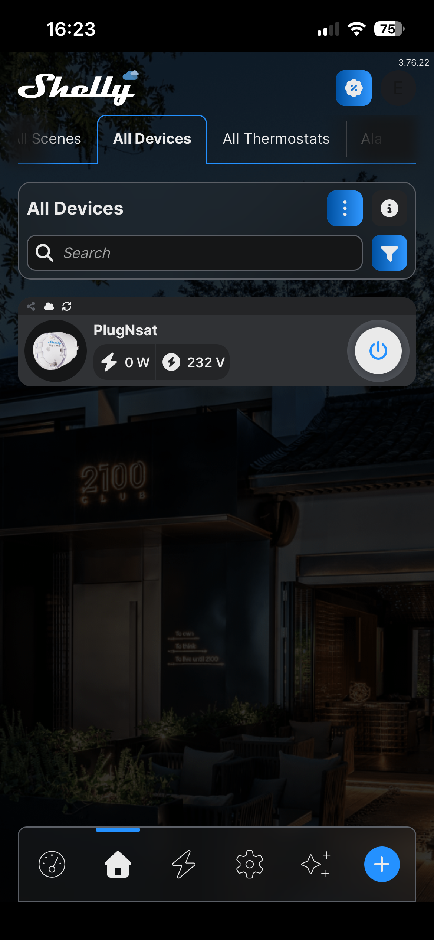
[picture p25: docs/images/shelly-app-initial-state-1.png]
All Devices tab showing the Shelly Plug


8. Under "Input/Output settings", select: "Configure Shelly device to Turn OFF when it has power." Tap "Save".

Input/Output settings with the Turn OFF option selected

9. Plug your target device (lamp, coffee machine, charger, etc.) into the Shelly. It should stay off.

---

## Step 3 — Power on the PlugNSat

1. Connect the PlugNSat to power using the USB-C cable
2. The splash screen appears for a few seconds

Splash screen

3. On first boot (or after a factory reset), the device enters **AP Setup Mode** and shows three boxes on screen:

AP mode screen

| Step | Value |
|---|---|
| WiFi name | `PlugNSat-Setup` |
| Password | `plugnsat21` |
| URL | `http://192.168.4.1` |

---

## Step 4 — Configure the PlugNSat

1. On your phone or computer, open WiFi settings and connect to `PlugNSat-Setup` (password: `plugnsat21`)
2. On the same device, open your browser and go to `http://192.168.4.1`
3. The web portal opens with 5 sections to complete:
   - WiFi
   - Lightning Backend
   - Shelly Plug
   - Device Settings
   - Security

### Step 1 of 5: WiFi

Enter the SSID and password of the WiFi network where the Shelly is connected.



### Step 2 of 5: Lightning Backend

Select your backend (BTCPay Server or Blink), then enter the credentials from Step 1 of this guide.

**BTCPay Server:**
- **Server URL** (no trailing slash, e.g. `https://btcpay.yourdomain.com`)
- **API Key** (the one you generated)
- **Store ID** (the long string from your store settings)

**Blink:**
- **API Key** (starts with `blink_`, generated at dashboard.blink.sv)
- **BTC Wallet ID** (find it on dashboard.blink.sv)

<p>
  
  
</p>

### Step 3 of 5: Shelly Plug

Click **Scan network** to automatically discover your Shelly on the local network. If it finds one, select it from the dropdown. Otherwise, type the Shelly hostname or IP address manually.



You can click **Test connection** to verify the PlugNSat can reach the Shelly.

### Step 4 of 5: Device Settings

- **Hardware model**: select **USB-C** for the mains-powered model or **Battery** for the LiPo model. Choosing Battery enables battery info on the Device Info screen and the Turn OFF (power-off) item in the settings menu. Pick the one matching your device.
- **Name**: a display name for your PlugNSat. If "Show name on QR screen" is enabled, the name is limited to 18 characters and may only contain letters, numbers, spaces, periods, and hyphens (no other special characters). If it is not shown on screen, up to 40 characters are allowed with no character restriction.
- **Show name on QR screen**: toggle to display the name next to the QR code
- **Price**: amount in satoshis the customer pays per activation
- **Duration**: how many seconds the Shelly stays on after a payment
- **Show price on QR screen**: toggle to display the price next to the QR code

You can also click **Simulate payment (free)** to test that the Shelly activates correctly.



### Step 5 of 5: Security

Both fields are optional. Leave them empty to skip.

- **Device PIN** (4 digits): prevents anyone near the device from changing the price and duration using the hardware buttons
- **Web Access Password**: protects this configuration page with a login prompt (username: `admin`). Always disabled in setup mode so you can never get locked out.



4. Click **Save and restart**
5. The PlugNSat reboots, connects to your WiFi, and the QR code appears on screen

<p>
  
  
</p>

Left: name and price displayed. Right: QR code only (both toggles off).

**You're live!** Customers can now scan and pay.

---

## Step 5 — Test a payment

### With a real wallet

1. Open any Lightning wallet (Phoenix, Wallet of Satoshi, Cash App, Blink, etc.)
2. Scan the QR code displayed on the PlugNSat
3. Confirm and pay the invoice
4. The PlugNSat shows the **PAID** screen with a countdown, and the Shelly turns on



5. After the configured duration, the Shelly turns off automatically and a new QR code appears

### With the simulator (free, no sats needed)

If you want to test without spending sats:

1. Connect to the same WiFi network as the PlugNSat
2. Open your browser and go to `http://plugnsat.local`. On Windows, if the page does not load, use the IP address shown instead (press BTN1 > **Device Info**).
3. In the **Device settings** section of the portal, click **Simulate payment (free)** — the Shelly should turn on.



This triggers the Shelly just like a real payment, without creating a Lightning invoice.

---

## Step 6 — Keeping your PlugNSat up to date

Open `http://plugnsat.local`. In the **Firmware update** section, click **Check for updates**. If a newer version is available, click **Install update** — the device downloads, verifies, flashes, and reboots on its own.

Prefer zero maintenance? Tick **Auto-update on boot** and the device checks and installs updates automatically every time it restarts.

---

## Next steps

- Read the [User Manual](user-manual.md) to learn about all screens and button controls
- Read the [Web Portal Reference](web-portal.md) for details on every configuration option
- Check the [Troubleshooting guide](troubleshooting.md) if something doesn't work

> Documentation is a work in progress. Some pages may not be available yet.

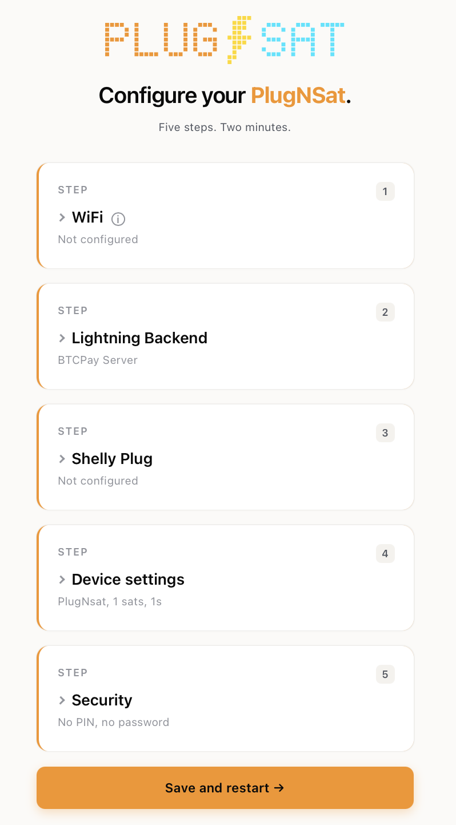
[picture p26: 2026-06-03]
docs/images/webportal-5-sections.png

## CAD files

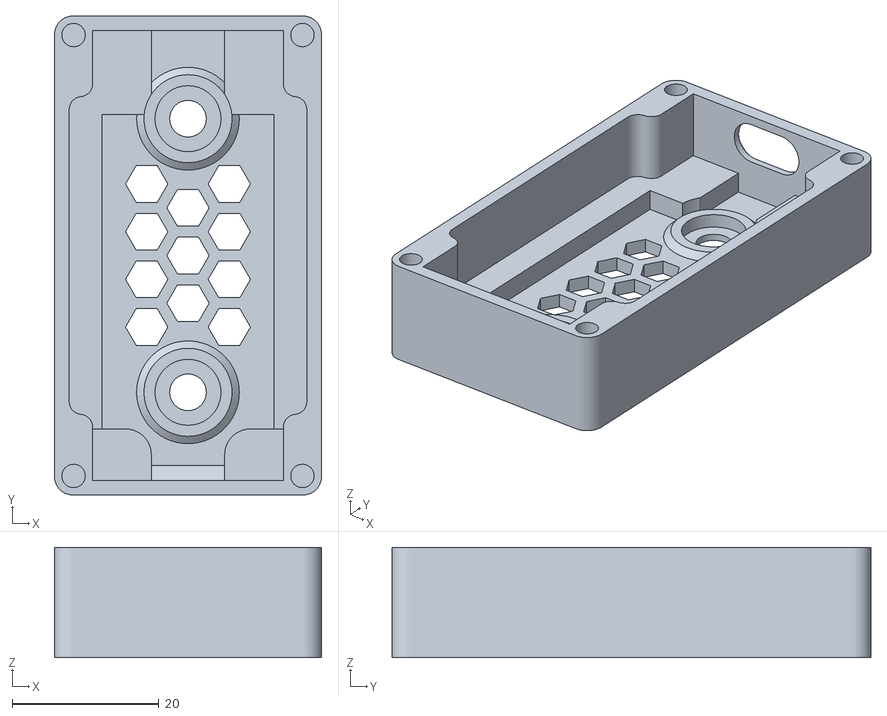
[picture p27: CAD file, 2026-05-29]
enclosure/stl/plugnsat-case_bottom.stl
36.4 x 65.3 x 15.0

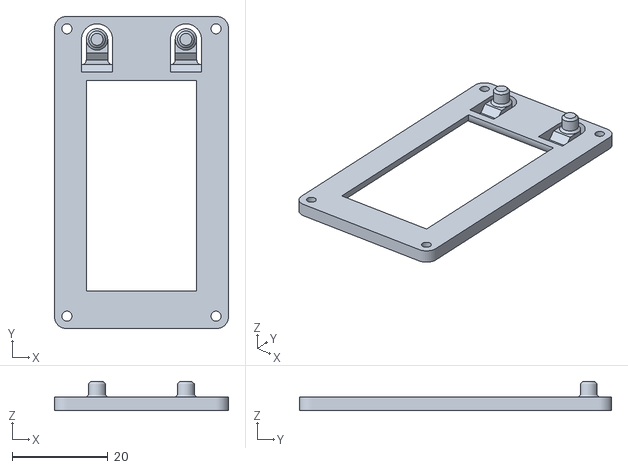
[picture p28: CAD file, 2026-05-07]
enclosure/stl/plugnsat-case-top.stl
36.4 x 65.3 x 6.10

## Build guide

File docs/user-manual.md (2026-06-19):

# User Manual

This document covers everything you need to know about using your PlugNSat day-to-day: what each screen means, how the buttons work, and how to adjust settings directly from the device.

## Overview

PlugNSat operates in a continuous loop:

1. The QR code is displayed permanently on screen
2. A customer scans and pays with any Lightning wallet
3. The screen shows "PAID" and the Shelly plug turns on
4. After the configured duration, the Shelly turns off
5. A new QR code appears automatically

No interaction from the operator is needed. The device runs autonomously.

---

## Buttons

The PlugNSat has two physical buttons on the top edge of the device.

| Button | Position | GPIO |
|---|---|---|
| BTN1 | Left (bottom on screen) | GPIO 0 |
| BTN2 | Right (top on screen) | GPIO 14 |

### Button actions

| Context | BTN1 (short press) | BTN1 (long press 3s) | BTN2 (short press) |
|---|---|---|---|
| QR screen | Open Settings menu | Enter AP Setup mode | Force QR refresh |
| Settings menu | Move cursor down | Enter AP Setup mode | Select option |
| Brightness | Decrease (-) | Enter AP Setup mode | Increase (+) |
| Price | Decrease (-) | Enter AP Setup mode | Increase (+) |
| Duration | Decrease (-) | Enter AP Setup mode | Increase (+) |
| PIN entry | Change digit (0-9) | Enter AP Setup mode | Confirm digit / Submit |
| Info screen | Return to QR | Enter AP Setup mode | Return to QR |
| AP mode screen | Reconnect to WiFi (if WiFi was configured) | n/a | Reconnect to WiFi |
| WiFi failed screen | Enter AP Setup mode | n/a | Retry connection |
| Error screen | Enter AP Setup mode | Enter AP Setup mode | Retry now (new QR) |
| Shelly offline screen | Return to QR (cancels retry) | Enter AP Setup mode | Return to QR (cancels retry) |

> **Long press BTN1 (3 seconds)** always enters AP Setup mode, from any screen. This is the universal "reconfigure" action. Use it if you need to change WiFi, backend, or Shelly settings.

---

## Screens

### Splash screen

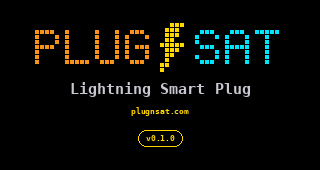
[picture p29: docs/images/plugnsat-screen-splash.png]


Displayed for 5 seconds on every boot. Shows the PLUG⚡SAT pixel art logo, the tagline "Lightning Smart Plug", the website URL, and the firmware version.

### Connecting

<p>
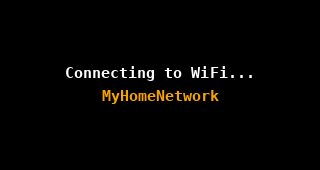
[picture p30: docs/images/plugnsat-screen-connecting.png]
    
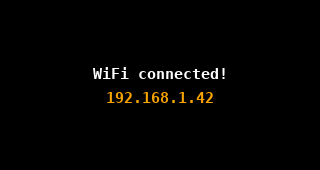
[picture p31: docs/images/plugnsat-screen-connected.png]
    
<p>

Appears while the device is connecting to your WiFi network. Shows the SSID it is trying to reach. If the connection succeeds, you briefly see the device's IP address before the QR screen loads.

If **Auto-update on boot** is enabled in the web portal, two extra screens may appear after the WiFi connection: "Checking updates..." and, if a new version is found, "Updating... vX.X.X" followed by an automatic reboot. See [Firmware updates](#firmware-updates).

### WiFi failed

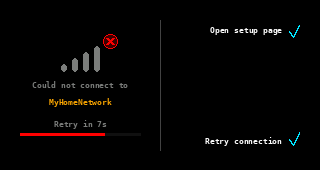
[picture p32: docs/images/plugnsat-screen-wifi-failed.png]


Appears if the device cannot connect to WiFi within 15 seconds. Shows the SSID it tried, a countdown before auto-retry (10 seconds), and two button options: BTN1 to enter AP Setup mode, BTN2 to retry immediately.

### QR code (main screen)

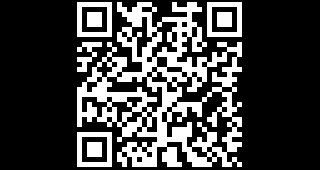
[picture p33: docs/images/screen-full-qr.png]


The primary operating screen. The QR code contains an LNURL that any Lightning wallet can scan. The QR auto-refreshes every 4 minutes 45 seconds (before the 5-minute invoice expiry) to always show a valid invoice.

If "Show name" and/or "Show price" are enabled in the web portal, the QR code shifts to the left and an info panel appears on the right side with the device name, price in sats, and the mini PLUG⚡SAT logo.

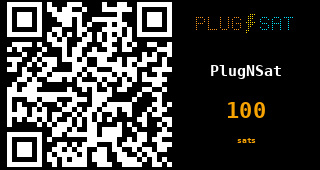
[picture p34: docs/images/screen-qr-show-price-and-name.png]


### Paid

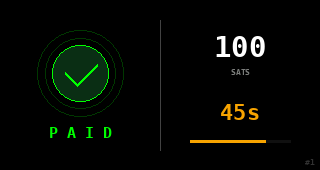
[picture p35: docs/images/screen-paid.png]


Appears when a payment is received. The screen brightness jumps to 100% to draw attention, and the screen is split in two halves:

- **Left**: a green checkmark with "PAID" underneath
- **Right**: the amount in sats, a countdown timer showing seconds remaining, a progress bar, and the payment counter (e.g. #3 for the third payment since boot)

The Shelly is ON during the entire countdown. When the countdown reaches zero, the Shelly turns off, the brightness returns to its configured level, and a new QR code appears.

### Error

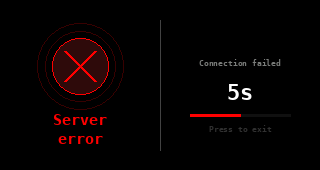
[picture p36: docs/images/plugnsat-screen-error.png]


Appears when the PlugNSat cannot reach the BTCPay Server (or Blink). The screen shows "Server error" and "Connection failed", with a countdown and "Press to exit". It retries automatically every 10 seconds.

- **BTN1**: enter AP Setup mode (to fix the configuration)
- **BTN2**: retry immediately

If payment polling fails 60 times in a row (about 5 minutes), the device restarts itself automatically.

> **This is normal.** After a prolonged loss of communication with the Lightning backend, the device reboots to restore a clean state. It will reconnect to WiFi and resume operation on its own. No action is needed from the operator.

### Shelly offline

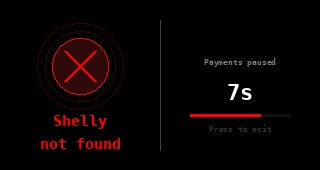
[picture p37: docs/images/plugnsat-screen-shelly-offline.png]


Appears if a payment was received but the Shelly could not be reached. The payment is still considered valid (the customer did pay).

The device automatically retries every 10 seconds. As soon as the Shelly comes back online, it is activated for the **full configured duration**, no matter how long it was offline. The customer paid for the full duration, so they get the full duration.

Pressing any button returns to the QR screen and **cancels the retry**. Only do this if you have handled the situation manually (e.g. activated the Shelly yourself or refunded the customer).

> **Important:** The customer is never charged twice. If the Shelly is offline, the payment still went through on the Lightning side.

### AP Setup mode

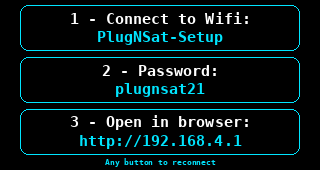
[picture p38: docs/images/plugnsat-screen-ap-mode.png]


Entered on first boot, or by long-pressing BTN1 (3 seconds) from any screen. The screen shows three boxes with connection instructions:

1. WiFi name: `PlugNSat-Setup`
2. Password: `plugnsat21`
3. URL: `http://192.168.4.1`

If a WiFi network was previously configured, pressing any button exits AP mode and reconnects to WiFi. Button presses are ignored during the first 3 seconds after entering AP mode, to avoid exiting it by accident.

> **AP mode is a configuration and recovery mode, not an operating mode.** While in AP mode, the web portal has no password protection — anyone connected to `PlugNSat-Setup` (password: `plugnsat21`) can access it freely. This is intentional so you can never lock yourself out. Once setup is done, press any button to return to WiFi. A Web Access Password configured in Step 5 of the portal only applies in normal (WiFi) mode.

---

## Settings menu

Press **BTN1** (short press) from the QR screen to enter the Settings menu.
<p>
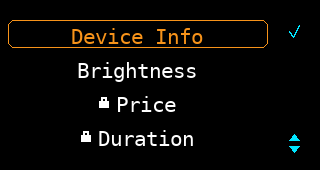
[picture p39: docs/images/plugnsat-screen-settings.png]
    
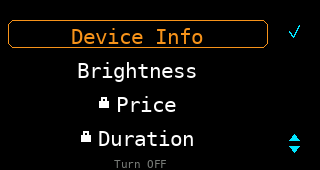
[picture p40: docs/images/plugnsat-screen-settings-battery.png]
    
<p>

The menu has 4 options on the USB-C model: Device Info, Brightness, Price, and Duration. On the battery model, a 5th option, Turn OFF, appears at the bottom (it puts the device into deep sleep; wake it with BTN1 or by connecting USB power). Use **BTN1** to move between options and **BTN2** to select.

### Device Info

<p>
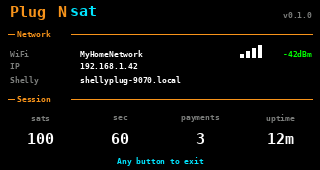
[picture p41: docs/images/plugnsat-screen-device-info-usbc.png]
    
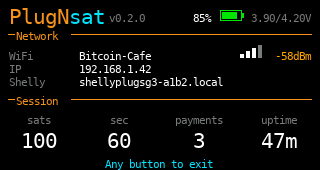
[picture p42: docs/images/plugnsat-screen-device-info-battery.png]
    
<p>

Displays a summary of the current device state. This information is useful for debugging and support:

- Firmware version (top-right corner)
- Battery percentage, icon, and voltage (battery model only)
- WiFi SSID and signal strength (RSSI)
- Device IP address (use `http://<device-IP-address>` to reach the web portal if `http://plugnsat.local` does not work; this IP can change)
- Shelly hostname
- Current price and duration
- Payment count since last boot
- Uptime

Press any button to return to the QR screen.

### Brightness

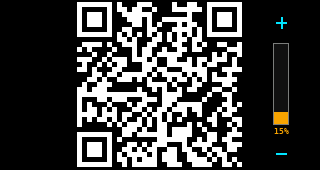
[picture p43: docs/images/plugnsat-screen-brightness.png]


Adjust the screen brightness. The QR code is displayed in the background at the current brightness so you can see the effect in real time.

- **BTN1**: decrease brightness (minimum: ~4%)
- **BTN2**: increase brightness (maximum: 100%)

A vertical bar and percentage indicator show the current level. The brightness is saved automatically and returns to the QR screen after 6 seconds of inactivity.

> **Tip:** Because this is an LED-backlit screen, maximum brightness is not always best for scanning. A setting around 21% usually gives the cleanest QR code reading, with less glare and better contrast for wallet cameras.

### Price

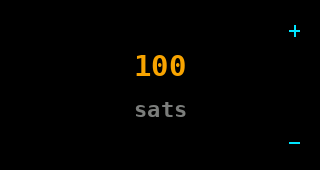
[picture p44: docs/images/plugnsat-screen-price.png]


Change the price in satoshis that customers pay per activation.

- **BTN1**: decrease (steps of 10 sats up to 1000, steps of 100 above; minimum: 1 sat)
- **BTN2**: increase (same stepping)

If a PIN is configured (set in the web portal), you must enter it before accessing this screen. The price is saved automatically and returns to the QR screen after 6 seconds of inactivity.

> **Note:** When you change the price, a new QR code is generated automatically with the updated price as soon as you leave this screen.

### Duration

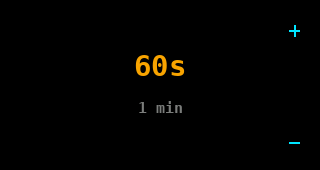
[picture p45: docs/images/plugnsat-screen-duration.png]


Change how long the Shelly stays on after a payment, in seconds.

- **BTN1**: decrease (steps of 10s up to 300s, steps of 60s above; minimum: 1s)
- **BTN2**: increase (same stepping, maximum: 86400s / 24 hours)

The screen also shows a human-readable conversion (e.g. "5 min", "1h 30min"). If a PIN is configured, you must enter it first. The duration is saved automatically and returns to the QR screen after 6 seconds of inactivity.

> **Note:** Changing the duration takes effect on the next payment, with no QR refresh needed.

### PIN entry

<p>
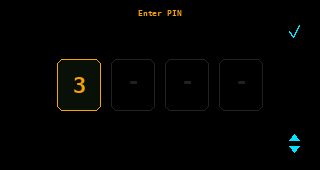
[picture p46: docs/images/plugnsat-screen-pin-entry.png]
    
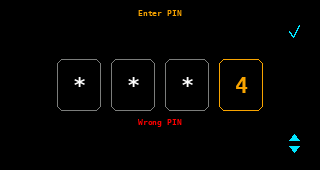
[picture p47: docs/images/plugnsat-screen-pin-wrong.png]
    
<p>

If you set a 4-digit PIN in the web portal, the PIN entry screen appears before accessing Price or Duration settings.

- **BTN1**: cycle the current digit (0 > 1 > 2 > ... > 9 > 0)
- **BTN2**: confirm current digit and move to next (or submit on the 4th digit)

Previous digits are masked with `*`. If the PIN is wrong, the screen flashes "Wrong PIN" and resets after 1.5 seconds. The PIN screen has a 15-second timeout (returns to settings if inactive).

---

## Firmware updates

PlugNSat can update its own firmware over WiFi. Updates are downloaded from the official PlugNSat releases and verified with a cryptographic signature before installation, so only authentic firmware can be installed.

There are two ways to update, both managed from the web portal:

### Manual update (recommended)

1. Open the web portal (device IP address or `http://plugnsat.local`)
2. In the **Firmware update** section, click **Check for updates**
3. If a new version is available, click **Install update**
4. The device downloads the firmware, verifies it, and reboots on the new version

You stay in full control: nothing is installed without your action.

### Auto-update on boot (opt-in)

Enable the **Auto-update on boot** checkbox in the web portal. From then on, every time the device restarts, it checks for a new version right after connecting to WiFi and installs it automatically. You will see "Checking updates..." and, if an update is found, "Updating... vX.X.X" before the device reboots.

If the update check or download fails, the device simply continues booting normally with its current firmware.

> **Tip:** The current firmware version is visible on the splash screen and on the Device Info screen.

---

## Auto-behaviors

These things happen automatically without any user action:

| Behavior | Trigger | What happens |
|---|---|---|
| QR refresh | Every 4 min 45 sec | New invoice created, QR updated silently |
| WiFi reconnect | WiFi connection lost | Automatic reconnection attempt |
| Error recovery | BTCPay/Blink unreachable | Retry every 10 seconds |
| Shelly retry | Shelly offline after payment | Retry every 10 seconds, full duration when back online |
| Auto-restart | 60 consecutive polling errors (~5 min) | ESP32 reboots itself |
| Auto-update | On boot, if enabled in web portal | Checks for new firmware, installs and reboots |
| Screen timeout | No button press for 6 sec (settings, brightness, price, duration) | Returns to QR screen, saves changes |
| PIN timeout | No button press for 15 sec | Returns to settings menu |

---

## Tips for daily use

- **Leave it running.** PlugNSat is designed to run continuously without intervention. When powered over USB-C (both the USB-C model and the battery model plugged in), it runs 24/7. On battery alone, the battery model runs for as long as the charge lasts.
- **Check the payment counter.** The number in the bottom-right of the Paid screen (#1, #2, #3...) counts payments since the last boot. Useful to know how many customers used it during the day.
- **Adjust price and duration on the fly.** No need to open the web portal for quick changes. Use the buttons (BTN1 from QR > Price or Duration).
- **Use a PIN** if the device is in a public place and you don't want someone to change the price or the duration.
- **The web portal is always available** at `http://plugnsat.local` or at the device's IP address on the same WiFi network. You can access it from your phone or laptop.
- **Keep your firmware up to date.** Check for updates from the web portal once in a while, or enable auto-update on boot if you prefer a hands-off approach.
- **Brightness matters for QR scanning.** A setting around 21% usually gives the cleanest QR read on this LED-backlit screen. If customers still have trouble scanning, adjust the brightness up or down. Screen reflections on the LCD can be an issue in bright environments.

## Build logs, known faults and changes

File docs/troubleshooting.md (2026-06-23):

# Troubleshooting

Common issues and how to fix them. If your problem is not listed here, open an issue on [GitHub](https://github.com/ezmo-dev/plugnsat/issues) or reach out on social media.

---

## WiFi issues

### The PlugNSat won't connect to WiFi

**Symptoms:** the "Connecting to WiFi..." screen stays for a while, then a "Could not connect" screen appears with a 10-second countdown before auto-retry.

**Things to check:**

1. **Is the SSID correct?** WiFi names are case-sensitive. "MyWiFi" and "mywifi" are different networks.
2. **Is the password correct?** Re-enter it in the web portal (AP Setup mode: long press BTN1 for 3 seconds, connect to `PlugNSat-Setup`, open `http://192.168.4.1`).
3. **Is it a 2.4 GHz network?** The ESP32-S3 does not support 5 GHz. If your router broadcasts both bands under the same name, try separating them in your router settings.
4. **Is the WiFi too far?** Move the PlugNSat closer to the router. Check the RSSI value on the Device Info screen (Settings menu, then Device Info). Anything weaker than -75 dBm may cause issues.
5. **Is the router blocking new devices?** Some routers have MAC filtering or a device limit. Check your router admin panel.

**Quick fix:** Long press BTN1 (3 seconds) to enter AP Setup mode, then re-enter your WiFi credentials.

> When the connection attempt fails, you have two options on the "Could not connect" screen: BTN1 enters AP Setup mode, BTN2 retries immediately. If you do nothing, the device retries automatically after the countdown.

### WiFi disconnects randomly

The PlugNSat checks the connection periodically and reconnects automatically when WiFi drops. If it happens frequently:

- Check your router's stability (are other devices also dropping?)
- Move the PlugNSat closer to the router
- Avoid placing the device behind metal objects or inside thick enclosures that block the WiFi signal

---

## QR code issues

### The QR code won't scan

**Most common causes:**

1. **Screen brightness not optimal.** Adjust brightness from the device (Settings menu, then Brightness, BTN2 to increase, BTN1 to decrease). Because this is an LED-backlit screen, maximum brightness is not always best. A setting around 21% usually gives the cleanest reading, with less glare and better contrast for wallet cameras.
2. **Screen reflections.** The LCD has a glossy surface. In bright environments (sunlight, strong overhead lights), angle the device or move it to reduce glare.
3. **Camera too close.** Hold the phone 15 to 25 cm away from the screen.
4. **Wallet doesn't support the invoice format.** With a BTCPay backend the QR uses LNURL, which most modern wallets support (Phoenix, Wallet of Satoshi, Blink, Cash App, Muun, Blue Wallet, Zeus). With a Blink backend the QR is a BOLT11 invoice, which is larger and denser. Try a different wallet if scanning fails.

### The QR code refreshes before the customer can scan

The QR auto-refreshes after 4 minutes 45 seconds (before the 5-minute invoice expiry). This is normal: it ensures the QR always shows a valid, payable invoice. If a customer sees the QR refresh while scanning, they can simply scan again. The new QR is immediately valid.

---

## Payment issues

### Payment was sent but the screen didn't change

**Possible causes:**

1. **Polling delay.** The PlugNSat checks for payment every 5 seconds. Wait a few seconds after the wallet confirms payment.
2. **Backend is slow.** Lightning invoice settlement can take a moment depending on channel liquidity and node performance. The device treats both "Settled" and "Processing" as paid, so a slow final settlement still triggers activation.
3. **WiFi issue.** If WiFi dropped between the payment and the poll, the PlugNSat may miss that poll. The device reconnects and picks up the status on the next poll.

### The Shelly didn't turn on after payment

**Symptoms:** The "PAID" screen appeared but the Shelly did not activate, or the "Shelly not found" screen appeared.

**Things to check:**

1. **Is the Shelly plugged in?** Check that it has power (LED indicator on the Shelly).
2. **Is the Shelly on the same WiFi?** Both devices must be on the same local network.
3. **Is the hostname correct?** Go to Device Info (BTN1 from QR) and check the "Shelly" field. If it shows an IP address, the Shelly may have changed IP via DHCP. Use the mDNS hostname instead (`.local`).
4. **Can the Shelly be reached?** Open the Shelly hostname or IP in a browser on the same network. You should see the Shelly web interface.

> **Note:** Even if the Shelly is offline, the customer's payment is still processed. The Lightning invoice was settled. You may need to activate the Shelly manually (via the Shelly app or by pressing the button on the Shelly itself).

### "Error" screen keeps appearing

This means the PlugNSat cannot reach the BTCPay Server (or Blink). The device retries automatically every 10 seconds.

**Things to check:**

1. **Is the BTCPay Server online?** Open the server URL in your browser.
2. **Is the API key valid?** API keys can be revoked. Generate a new one if needed.
3. **Did the server URL change?** If you migrated your BTCPay instance, update the URL in the web portal.
4. **Is the Lightning node working?** Log into BTCPay > Settings > Lightning and check the status.

If the device encounters 10 consecutive errors, it restarts itself automatically to recover from potential memory or connection issues.

---

## Shelly issues

### "Scan network" doesn't find the Shelly

**Possible causes:**

1. **Shelly is on a different network.** Both devices must be on the same WiFi network and subnet.
2. **mDNS is blocked.** Some routers block multicast DNS traffic. Try entering the Shelly's IP address manually instead.
3. **Shelly is not powered on.** Make sure the Shelly has power (check its LED).

**Manual alternative:** Open the Shelly app, find your device, and note the hostname or IP address. Enter it manually in the web portal's Shelly hostname field.

### The Shelly turns on but the connected device doesn't

1. **Check the device plugged into the Shelly.** Is it actually turned on (power switch in the "on" position)? Some devices have their own on/off switch.
2. **Check the Shelly's max power rating.** The Shelly Plug S Gen3 supports up to 2500W. If your device draws more, the Shelly will not switch.
3. **Check the wall outlet.** Try plugging the device directly into the wall to confirm it works.

---

## Web portal issues

### Can't access the web portal at 192.168.4.1

This address only works in **AP Setup mode** (when the device is broadcasting its own WiFi network). If the device is connected to your regular WiFi:

1. Find the device's IP address on the Device Info screen (BTN1 from QR)
2. Open `http://<device-ip>` in your browser on the same network

### Can't access the web portal at the device's IP

1. **Are you on the same WiFi?** The portal is only accessible on the local network.
2. **Try refreshing.** The first connection can take a second while the ESP32 serves the page.
3. **Try a different browser.** Some browsers aggressively redirect HTTP to HTTPS. The web portal uses HTTP (no SSL). Try typing the URL manually including `http://`.

### Settings don't save

If you click "Save and restart" but the settings revert to old values:

1. Make sure you filled in all required fields (WiFi SSID, BTCPay URL, API Key, Store ID)
2. Try again from AP mode (long press BTN1) for a fresh connection

---

## AP mode issues

### I'm stuck in AP mode

If the device keeps entering AP mode on every boot, it means no WiFi credentials are saved. Enter the web portal (`http://192.168.4.1`), fill in your WiFi credentials, and click Save and restart.

### I can't find "PlugNSat-Setup" in my WiFi list

1. Wait 10 seconds after the AP mode screen appears. The WiFi broadcast can take a moment.
2. On your phone, pull down to refresh the WiFi list.
3. Move closer to the PlugNSat (within 2 meters).
4. If still not visible, try power-cycling the PlugNSat (unplug and replug USB-C).

---

## BTCPay Server specific issues

### "Invoice error 401" or "Invoice error 403"

This means the API key is invalid or doesn't have the right permissions.

1. Go to BTCPay Server > Account > Manage Account > API Keys
2. Check that your key has: `cancreateinvoice`, `canviewinvoices`, `canuselightningnode`
3. If unsure, revoke the old key and create a new one

### "No LNURL found"

This means the BTCPay Server returned the invoice but the LNURL payment method is missing.

1. Make sure your store has Lightning enabled (Settings > Lightning)
2. Make sure LNURL is enabled in your store's Lightning settings
3. Check that the payment method ID is `BTC-LNURL` (recent BTCPay versions changed the naming from `BTC-LightningNetwork`)

---

## Factory reset

To reset the PlugNSat to its default state:

1. Long press BTN1 (3 seconds) to enter AP Setup mode
2. Connect to `PlugNSat-Setup` WiFi
3. Open `http://192.168.4.1`
4. Clear all fields and save, or simply re-enter new credentials

> There is no "erase all" button yet. All settings are stored in the ESP32's non-volatile memory. Reflashing the firmware also clears all settings.

---

## Getting help

If none of the above solves your problem:

1. Open an issue on [GitHub](https://github.com/ezmo-dev/plugnsat/issues) with:
   - Your firmware version (shown on the splash screen)
   - A description of the issue
   - Photos of the screen if relevant
2. Check the [PlugNSat website](https://plugnsat.com) for updates
3. Reach out on Twitter/Nostr to [@ezmo-dev](https://twitter.com/ezmo_dev)

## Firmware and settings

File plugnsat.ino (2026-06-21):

/*
 * PlugNSat - Main Firmware
 * Lightning Smart Plug Controller
 * Version: see FIRMWARE_VERSION in config.h
 * Hardware: LilyGO T-Display S3 (ESP32-S3 + 1.9" LCD)
 * 
 * BASED ON:
 * - BitcoinSwitch by @arcbtc: github.com/arcbtc/bitcoinSwitch
 * - LNPoS by @arcbtc: github.com/arcbtc/LNPoS
 * 
 * HARDWARE:
 * - LilyGO T-Display S3 (ESP32-S3 + ST7789 1.9" LCD)
 * - Shelly Plug S Gen3 (WiFi relay, CE certified, 2500W)
 * - Lightning backend: BTCPay Server (Phoenixd, LND, CLN) or Blink
 * 
 * WORKFLOW:
 *   1. First boot: Welcome screen, AP mode for setup via web browser (webportal)
 *   2. Once configured: QR code LNURL displayed permanently (passive PoS)
 *   3. Customer scans and pays with any Lightning wallet
 *   4. "Payment received!" screen, Shelly activates (duration configured on webportal)
 *   5. New QR code auto-generated, cycle repeats
 *   6. QR auto-refreshes every 4m45s (before 5min expiry)
 *
 * BUTTONS (T-Display S3 built-in):
 *   - Button 1 (GPIO 0):  Settings menu / Long press = AP mode
 *   - Button 2 (GPIO 14): Force refresh QR / Confirm
 * 
 * License: MIT © 2026
 * Author: ezmo-dev (PlugNSat)
 */

// OTA NOTE (Arduino IDE):
// Board: ESP32S3 Dev Module
// Partition Scheme: select "Minimal SPIFFS (1.9MB APP with OTA/128KB SPIFFS)"
// This provides two OTA app slots required for firmware updates.
// Do not use a "No OTA" partition scheme.

#include <WiFi.h>
#include <HTTPClient.h>
#include <WiFiClientSecure.h>
#include <WebServer.h>
#include <Preferences.h>
#include <ArduinoJson.h>
#include <ESPmDNS.h>
#include <TFT_eSPI.h>
#include "qrcode.h"
#include "config.h"
#include "display.h"
#include "btcpay.h"
#include "shelly.h"
#include "backend.h"
#include "ota.h"
#include "webportal.h"
#include "esp_sleep.h"
#include <driver/rtc_io.h>

//
// GLOBALS
//

TFT_eSPI tft = TFT_eSPI();
Preferences prefs;
WebServer server(80);

// Buttons
#define BTN_1   0
#define BTN_2   14

bool btn1Pressed = false;
bool btn2Pressed = false;

// State machine
enum AppState {
  STATE_AP_SETUP,
  STATE_CONNECTING,
  STATE_QR_DISPLAY,
  STATE_PAID,
  STATE_ERROR,
  STATE_SHELLY_OFFLINE,
  STATE_INFO,
  STATE_SETTINGS,
  STATE_BRIGHTNESS,
  STATE_PRICE,
  STATE_DURATION,
  STATE_PIN_ENTRY
};
AppState currentState = STATE_CONNECTING;

// Invoice tracking
String currentInvoiceId = "";
String currentQRData     = "";
unsigned long invoiceCreatedAt = 0;
unsigned long lastPollTime     = 0;

// Error tracking
int consecutiveErrors = 0;
unsigned long errorStartTime = 0;
unsigned long shellyOfflineStartTime = 0;
unsigned long paidStartTime = 0;
bool paidShellyTriggered = false;

// Session stats
int paymentCount = 0;

// Settings menu
int settingsIndex = 0;
unsigned long lastSettingsInput = 0;
unsigned long lastBrightnessInput = 0;
unsigned long lastPriceInput = 0;
unsigned long lastDurationInput = 0;
int priceOnEnterMenu = 0;

// PIN entry
int pinEntry[4] = {0, 0, 0, 0};
int pinDigitIndex = 0;
AppState pinTargetState = STATE_PRICE;
unsigned long lastPinInput = 0;
bool pinWrong = false;
unsigned long pinWrongTime = 0;

// AP mode
unsigned long apModeStartTime = 0;

// WiFi monitoring
unsigned long lastWifiCheck = 0;

// Heap monitoring
unsigned long lastHeapLog = 0;

// Display
bool screenNeedsRedraw = true;

// Config
PlugNSatConfig config;

// Battery
int batteryMv = 0;              // Last measured battery voltage in mV
unsigned long lastBatRead = 0;  // Last read timestamp
int prevBatteryMv = 0;        // previous reading, for charge trend
bool isCharging = false;      // true if voltage is rising
int chargeRiseCount = 0;      // consecutive rising readings
int lowBatCount = 0;          // consecutive readings below cutoff
bool lowBatBlinkOn = false;        // current blink phase
unsigned long lastLowBatBlink = 0; // last blink toggle

//
// SETUP
//

void setup() {
  gpio_hold_dis((gpio_num_t)15);
  pinMode(15, OUTPUT);
  digitalWrite(15, HIGH);
  otaInit();
  Serial.begin(115200);
  delay(500);
  Serial.println("\n\n=== PlugNSat v" FIRMWARE_VERSION " ===");

  tft.init();
  tft.setRotation(1);
  ledcAttach(BACKLIGHT_PIN, 5000, 8);
  ledcWrite(BACKLIGHT_PIN, 40);
  tft.fillScreen(TFT_BLACK);
  tft.setSwapBytes(true);
  
  pinMode(BTN_1, INPUT_PULLUP);
  pinMode(BTN_2, INPUT_PULLUP);

  loadConfig();
  delay(100);
  readBatteryMv();              // discard first unstable reading
  batteryMv = readBatteryMv();  // real value
  initBackend(config.backendType);
  ledcWrite(BACKLIGHT_PIN, 255);
  displaySplash(tft);
  delay(5000);
  ledcWrite(BACKLIGHT_PIN, config.brightness);

  bool hasBackendConfig = false;
  if (config.backendType == BACKEND_BTCPAY) {
    hasBackendConfig = config.btcpayUrl.length() > 0 && config.btcpayApiKey.length() > 0;
  } else if (config.backendType == BACKEND_BLINK) {
    hasBackendConfig = config.blinkApiKey.length() > 0 && config.blinkWalletId.length() > 0;
  }

  if (config.wifiSsid.length() == 0 || !hasBackendConfig) {
    startAPMode();
  } else {
    connectToWiFi();
  }
}

//
// MAIN LOOP
//

void loop() {
  if (millis() - lastBatRead > BAT_READ_INTERVAL_MS) {
    lastBatRead = millis();
    int fresh = readBatteryMv();
    if (prevBatteryMv > 0) {
      if (fresh > prevBatteryMv + CHARGE_RISE_MV) {
        chargeRiseCount++;
      } else {
        chargeRiseCount = 0;
      }
      // need a sustained rise over several samples, not a single rebound
      isCharging = (chargeRiseCount >= CHARGE_RISE_SAMPLES);
    }
    prevBatteryMv = fresh;
    batteryMv = fresh;
    // Software low-voltage cutoff, battery model only, not while charging
    if (config.isBattery && !isCharging && fresh > 0 && fresh <= VBAT_CUTOFF_MV) {
      lowBatCount++;
      if (lowBatCount >= VBAT_CUTOFF_COUNT) {
        enterLowBatterySleep();
      }
    } else {
      lowBatCount = 0;
    }
  }
  otaTick();
  server.handleClient();
  readButtons();

  switch (currentState) {
    case STATE_AP_SETUP:
      loopAPSetup();
      break;

    case STATE_QR_DISPLAY:
      loopQRDisplay();
      break;

    case STATE_PAID:
      loopPaid();
      break;

    case STATE_ERROR:
      loopError();
      break;

    case STATE_SHELLY_OFFLINE:
      loopShellyOffline();
      break;

    case STATE_INFO:
      loopInfo();
      break;

    case STATE_SETTINGS:
      loopSettings();
      break;

    case STATE_BRIGHTNESS:
      loopBrightness();
      break;

    case STATE_PRICE:
      loopPrice();
      break;

    case STATE_DURATION:
      loopDuration();
      break;

    case STATE_PIN_ENTRY:
      loopPinEntry();
      break;

    default:
      break;
  }
  
  delay(10);
}

//
// WIFI
//

void connectToWiFi() {
  displayConnecting(tft, config.wifiSsid);
  
  WiFi.mode(WIFI_STA);
  WiFi.setAutoReconnect(true);
  WiFi.begin(config.wifiSsid.c_str(), config.wifiPass.c_str());
  
  int attempts = 0;
  while (WiFi.status() != WL_CONNECTED && attempts < 30) {
    delay(500);
    attempts++;
  }
  
  if (WiFi.status() == WL_CONNECTED) {
    Serial.println("WiFi OK: " + WiFi.localIP().toString());
    otaMarkValid();
    MDNS.begin("plugnsat");
    displayStatus(tft, "WiFi connected!", WiFi.localIP().toString());
    delay(1500);

    // Auto-update on boot (opt-in)
    if (config.autoUpdate) {
      displayStatus(tft, "Checking updates...", "");
      OtaUpdateInfo upd = otaCheckUpdate();
      if (upd.error.length() == 0 && upd.available) {
        Serial.println("OTA: auto-update on boot to v" + upd.latestVersion);
        displayStatus(tft, "Updating...", "v" + upd.latestVersion);
        OtaFlashResult fr = otaDownloadAndFlash(upd.latestVersion);
        if (fr.success) {
          Serial.println("OTA: boot auto-update success, rebooting");
          delay(500);
          ESP.restart();
        } else {
          Serial.println("OTA: boot auto-update failed: " + fr.error);
          // Continue normal boot on failure
        }
      } else {
        Serial.println("OTA: no boot update (err=" + upd.error
                       + " avail=" + String(upd.available) + ")");
      }
    }

    setupWebPortal(server, config, prefs);
    server.begin();

    generateAndShowQR();
  } else {
    Serial.println("WiFi FAILED");

    unsigned long t = millis();
    int lastSecond = -1;
    while (millis() - t < WIFI_RETRY_WINDOW_MS) {
      readButtons();
      if (btn1Pressed) { startAPMode(); return; }
      if (btn2Pressed) { connectToWiFi(); return; }
      server.handleClient();
      int secondsLeft = max(0, 10 - (int)((millis() - t) / 1000));
      if (secondsLeft != lastSecond) {
        lastSecond = secondsLeft;
        displayWiFiFailed(tft, config.wifiSsid, secondsLeft);
      }
      delay(50);
    }
    connectToWiFi();  // Auto-retry
  }
}

bool ensureWiFi() {
  if (millis() - lastWifiCheck < WIFI_CHECK_INTERVAL_MS) return WiFi.status() == WL_CONNECTED;
  lastWifiCheck = millis();
  
  if (WiFi.status() != WL_CONNECTED) {
    Serial.println("WiFi lost, reconnecting...");
    WiFi.disconnect();
    delay(1000);
    WiFi.begin(config.wifiSsid.c_str(), config.wifiPass.c_str());
    
    int att = 0;
    while (WiFi.status() != WL_CONNECTED && att < 20) { delay(500); att++; }
    
    if (WiFi.status() != WL_CONNECTED) {
      currentState = STATE_ERROR;
      errorStartTime = millis();
      return false;
    }
    Serial.println("WiFi reconnected");
  }
  return true;
}

//
// QR DISPLAY (main operating loop)
//

void loopQRDisplay() {
  if (!ensureWiFi()) return;

  if (millis() - lastHeapLog > HEAP_LOG_MS) {
    lastHeapLog = millis();
    Serial.println("Heap free: " + String(ESP.getFreeHeap()) + " bytes");
  }

  // Auto-refresh QR before expiry (4min 45s = 285000ms)
  if (millis() - invoiceCreatedAt > QR_REFRESH_MS) {
    Serial.println("QR refresh (expiry prevention)");
    generateAndShowQR();
    return;
  }
  
  // BTCPay polling and Shelly activation
  if (millis() - lastPollTime > POLL_INTERVAL_MS) {
    lastPollTime = millis();
    
    String status = backend.checkInvoice(config, currentInvoiceId, currentQRData);
    
    if (status == "ERROR") {
      consecutiveErrors++;
      Serial.println("Poll error #" + String(consecutiveErrors));
      if (consecutiveErrors >= MAX_CONSECUTIVE_ERRORS) {
        displayError(tft, WiFi.localIP().toString(), 5);
        delay(5000);
        ESP.restart();
      }
      return;
    }
    
    consecutiveErrors = 0;
    
    if (status == "Settled" || status == "Processing") {
      Serial.println("*** PAYMENT RECEIVED ***");
      paidStartTime = millis();
      paidShellyTriggered = false;
      paymentCount++;
      ledcWrite(BACKLIGHT_PIN, 255);
      currentState = STATE_PAID;
      return;
    }
    
    if (status == "Expired" || status == "Invalid") {
      Serial.println("Invoice expired, refreshing");
      generateAndShowQR();
      return;
    }
  }
  
  // Low battery warning: blink crossed-out icon, battery model only
  if (config.isBattery && batteryMv > 0 && batteryMv <= VBAT_LOW_MV) {
    if (millis() - lastLowBatBlink > LOWBAT_BLINK_MS) {
      lastLowBatBlink = millis();
      lowBatBlinkOn = !lowBatBlinkOn;
      drawLowBatteryWarning(tft, lowBatBlinkOn);
    }
  }

  // Buttons
  if (btn1Pressed) {
    settingsIndex = 0;
    lastSettingsInput = millis();
    currentState = STATE_SETTINGS;
    screenNeedsRedraw = true;
  }
  if (btn2Pressed) {
    generateAndShowQR();  // Force refresh
  }
}

void returnToQR() {
  if (currentQRData.length() > 0) {
    showCurrentQR();
  } else {
    generateAndShowQR();
  }
}

void showCurrentQR() {
  if (config.showName || config.showPrice) {
    displayQRWithInfo(tft, currentQRData, config.priceSats, config.deviceName, config.showName, config.showPrice);
  } else {
    displayQR(tft, currentQRData, config.priceSats, config.deviceName);
  }
  currentState = STATE_QR_DISPLAY;
}

void generateAndShowQR() {
  if (currentInvoiceId.length() > 0) {
    String status = backend.checkInvoice(config, currentInvoiceId, currentQRData);
    if (status == "Settled" || status == "Processing") {
      Serial.println("*** PAYMENT DETECTED before QR refresh ***");
      paidStartTime = millis();
      paidShellyTriggered = false;
      paymentCount++;
      ledcWrite(BACKLIGHT_PIN, 255);
      currentState = STATE_PAID;
      return;
    }
  }

  for (int attempt = 0; attempt < 3; attempt++) {
    displayGenerating(tft);

    String invoiceId, lnurl;

    bool ok = backend.createInvoice(config, config.priceSats, invoiceId, lnurl);

    if (ok && lnurl.length() > 0) {
      currentInvoiceId = invoiceId;
      currentQRData = lnurl;
      invoiceCreatedAt = millis();
      lastPollTime = millis();
      consecutiveErrors = 0;

      showCurrentQR();

      Serial.println("QR ready. Invoice: " + invoiceId + " (" + String(lnurl.length()) + " chars)");
      return;
    }

    consecutiveErrors++;
    delay(2000);
  }

  currentState = STATE_ERROR;
  errorStartTime = millis();
}

//
// PAID
//

void loopPaid() {
  if (!paidShellyTriggered) {
    paidShellyTriggered = true;
    bool shellyOk = shellySwitchOn(config.shellyHost, config.activationDuration);
    if (!shellyOk) {
      Serial.println("Shelly offline at payment — showing offline screen");
      ledcWrite(BACKLIGHT_PIN, config.brightness);
      shellyOfflineStartTime = millis();
      currentState = STATE_SHELLY_OFFLINE;
      return;
    }
    Serial.println("Shelly ON for " + String(config.activationDuration) + "s");
  }

  int secondsLeft = max(0, config.activationDuration - (int)((millis() - paidStartTime) / 1000));

  static int lastDisplayedSecond = -1;
  if (secondsLeft != lastDisplayedSecond) {
    lastDisplayedSecond = secondsLeft;
    displayPaid(tft, paymentCount, config.priceSats, secondsLeft, config.activationDuration);
  }

  if (millis() - paidStartTime >= (unsigned long)config.activationDuration * 1000) {
    lastDisplayedSecond = -1;
    ledcWrite(BACKLIGHT_PIN, config.brightness);
    currentInvoiceId = "";
    currentQRData = "";
    generateAndShowQR();
  }
}

//
// ERROR (auto-retry after 10s)
//

void loopError() {
  ledcWrite(BACKLIGHT_PIN, 255);

  int secondsLeft = max(0, 10 - (int)((millis() - errorStartTime) / 1000));

  static int lastDisplayedSecond = -1;
  if (secondsLeft != lastDisplayedSecond) {
    lastDisplayedSecond = secondsLeft;
    displayError(tft, WiFi.localIP().toString(), secondsLeft);
  }

  if (millis() - errorStartTime > ERROR_RETRY_MS) {
    lastDisplayedSecond = -1;
    consecutiveErrors = 0;
    ledcWrite(BACKLIGHT_PIN, config.brightness);
    generateAndShowQR();
    return;
  }
  if (btn1Pressed) { lastDisplayedSecond = -1; ledcWrite(BACKLIGHT_PIN, config.brightness); startAPMode(); }
  if (btn2Pressed) { lastDisplayedSecond = -1; ledcWrite(BACKLIGHT_PIN, config.brightness); consecutiveErrors = 0; generateAndShowQR(); }
}

//
// SHELLY OFFLINE
//

void loopShellyOffline() {
  int secondsLeft = max(0, 10 - (int)((millis() - shellyOfflineStartTime) / 1000));

  static int lastDisplayedSecond = -1;
  if (secondsLeft != lastDisplayedSecond) {
    lastDisplayedSecond = secondsLeft;
    displayShellyOffline(tft, secondsLeft);
  }

  if (btn1Pressed || btn2Pressed) {
    lastDisplayedSecond = -1;
    ledcWrite(BACKLIGHT_PIN, config.brightness);
    generateAndShowQR();
    return;
  }

  if (millis() - shellyOfflineStartTime > SHELLY_OFFLINE_RETRY_MS) {
    lastDisplayedSecond = -1;
    if (shellyIsOnline(config.shellyHost)) {
      Serial.println("Shelly back online, retrying activation");
      bool ok = shellySwitchOn(config.shellyHost, config.activationDuration);
      if (ok) {
        Serial.println("Shelly ON for " + String(config.activationDuration) + "s (retry after offline)");
      }
      lastDisplayedSecond = -1;
      paidStartTime = millis();
      paidShellyTriggered = true;
      currentInvoiceId = "";
      currentQRData = "";
      ledcWrite(BACKLIGHT_PIN, 255);
      currentState = STATE_PAID;
    } else {
      Serial.println("Shelly still offline, retrying in 10s");
      shellyOfflineStartTime = millis();
    }
  }
}

//
// INFO
//

void loopInfo() {
  if (screenNeedsRedraw) {
    displayInfo(tft, config, paymentCount, batteryMv, isCharging);
    screenNeedsRedraw = false;
  }
  if (btn1Pressed || btn2Pressed) {
    returnToQR();
  }
}

//
// SETTINGS
//

void loopSettings() {
  // Auto-timeout 6s -> back to QR
  if (millis() - lastSettingsInput > MENU_TIMEOUT_MS) {
    returnToQR();
    return;
  }
  if (screenNeedsRedraw) {
    displaySettings(tft, settingsIndex, config.pin.length() == 4, config.isBattery);
    screenNeedsRedraw = false;
  }
  if (btn1Pressed) {
    lastSettingsInput = millis();
    settingsIndex = (settingsIndex + 1) % (config.isBattery ? 5 : 4);
    screenNeedsRedraw = true;
  }
  if (btn2Pressed) {
    lastSettingsInput = millis();
    if (settingsIndex == 0) {
      currentState = STATE_INFO;
      screenNeedsRedraw = true;
    } else if (settingsIndex == 1) {
      lastBrightnessInput = millis();
      currentState = STATE_BRIGHTNESS;
      screenNeedsRedraw = true;
    } else if (settingsIndex == 2) {
      if (config.pin.length() == 4) {
        pinDigitIndex = 0;
        for (int i = 0; i < 4; i++) pinEntry[i] = 0;
        pinWrong = false;
        pinTargetState = STATE_PRICE;
        lastPinInput = millis();
        currentState = STATE_PIN_ENTRY;
      } else {
        priceOnEnterMenu = config.priceSats;
        lastPriceInput = millis();
        currentState = STATE_PRICE;
      }
      screenNeedsRedraw = true;
    } else if (settingsIndex == 3) {
      if (config.pin.length() == 4) {
        pinDigitIndex = 0;
        for (int i = 0; i < 4; i++) pinEntry[i] = 0;
        pinWrong = false;
        pinTargetState = STATE_DURATION;
        lastPinInput = millis();
        currentState = STATE_PIN_ENTRY;
      } else {
        lastDurationInput = millis();
        currentState = STATE_DURATION;
      }
      screenNeedsRedraw = true;
    } else if (settingsIndex == 4 && config.isBattery) {
      enterManualSleep();
    }
  }
}

//
// BRIGHTNESS
//

void loopBrightness() {
  // Auto-save and return to QR after 3s without input
  if (millis() - lastBrightnessInput > MENU_TIMEOUT_MS) {
    saveConfig();
    returnToQR();
    return;
  }
  if (screenNeedsRedraw) {
    displayBrightness(tft, config.brightness, currentQRData);
    screenNeedsRedraw = false;
  }
  if (btn1Pressed) {
    lastBrightnessInput = millis();
    config.brightness = max(10, config.brightness - 10);
    ledcWrite(BACKLIGHT_PIN, config.brightness);
    screenNeedsRedraw = true;
  }
  if (btn2Pressed) {
    lastBrightnessInput = millis();
    config.brightness = min(255, config.brightness + 10);
    ledcWrite(BACKLIGHT_PIN, config.brightness);
    screenNeedsRedraw = true;
  }
}

//
// PRICE
//

void loopPrice() {
  if (millis() - lastPriceInput > MENU_TIMEOUT_MS) {
    saveConfig();
    if (config.priceSats != priceOnEnterMenu) {
      generateAndShowQR();
    } else {
      returnToQR();
    }
    return;
  }
  if (screenNeedsRedraw) {
    displayPrice(tft, config.priceSats);
    screenNeedsRedraw = false;
  }
  if (btn1Pressed) {
    lastPriceInput = millis();
    int step = (config.priceSats <= 1000) ? 10 : 100;
    config.priceSats = max(1, config.priceSats - step);
    screenNeedsRedraw = true;
  }
  if (btn2Pressed) {
    lastPriceInput = millis();
    int step = (config.priceSats <= 1000) ? 10 : 100;
    config.priceSats += step;
    screenNeedsRedraw = true;
  }
}

//
// DURATION
//

void loopDuration() {
  if (millis() - lastDurationInput > MENU_TIMEOUT_MS) {
    saveConfig();
    returnToQR();
    return;
  }
  if (screenNeedsRedraw) {
    displayDuration(tft, config.activationDuration);
    screenNeedsRedraw = false;
  }
  if (btn1Pressed) {
    lastDurationInput = millis();
    int step = (config.activationDuration <= 300) ? 10 : 60;
    config.activationDuration = max(1, config.activationDuration - step);
    screenNeedsRedraw = true;
  }
  if (btn2Pressed) {
    lastDurationInput = millis();
    int step = (config.activationDuration <= 300) ? 10 : 60;
    config.activationDuration = min(86400, config.activationDuration + step);
    screenNeedsRedraw = true;
  }
}

//
// PIN ENTRY
//

void loopPinEntry() {
  // 15s timeout -> back to settings
  if (millis() - lastPinInput > PIN_TIMEOUT_MS) {
    currentState = STATE_SETTINGS;
    screenNeedsRedraw = true;
    return;
  }
  // Clear wrong PIN message after 1.5s and reset
  if (pinWrong && millis() - pinWrongTime > PIN_WRONG_MS) {
    pinWrong = false;
    pinDigitIndex = 0;
    for (int i = 0; i < 4; i++) pinEntry[i] = 0;
    screenNeedsRedraw = true;
  }
  if (screenNeedsRedraw) {
    displayPinEntry(tft, pinEntry, pinDigitIndex, pinWrong);
    screenNeedsRedraw = false;
  }
  if (btn1Pressed && !pinWrong) {
    lastPinInput = millis();
    pinEntry[pinDigitIndex] = (pinEntry[pinDigitIndex] + 1) % 10;
    screenNeedsRedraw = true;
  }
  if (btn2Pressed && !pinWrong) {
    lastPinInput = millis();
    if (pinDigitIndex < 3) {
      pinDigitIndex++;
      screenNeedsRedraw = true;
    } else {
      String entered = "";
      for (int i = 0; i < 4; i++) entered += String(pinEntry[i]);
      if (entered == config.pin) {
        if (pinTargetState == STATE_PRICE) {
          priceOnEnterMenu = config.priceSats;
          lastPriceInput = millis();
          currentState = STATE_PRICE;
        } else {
          lastDurationInput = millis();
          currentState = STATE_DURATION;
        }
        screenNeedsRedraw = true;
      } else {
        pinWrong = true;
        pinWrongTime = millis();
        screenNeedsRedraw = true;
      }
    }
  }
}

//
// AP MODE
//
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

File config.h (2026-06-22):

/*
 * PlugNSat - Configuration
 * 
 * Global constants, timing, QR code settings, and config structure
 * 
 * License: MIT © 2026
 * Author: ezmo-dev (PlugNSat)
 */

#ifndef CONFIG_H
#define CONFIG_H

#include <Arduino.h>

// Timing
#define POLL_INTERVAL_MS   5000      // Check payment status every 5s
#define QR_REFRESH_MS      285000    // Refresh QR at 4min45s (before 5min expiry)
#define INVOICE_EXPIRY_MIN 5         // BTCPay invoice expiration
#define FIRMWARE_VERSION   "0.2.0"
#define BACKLIGHT_PIN      38
#define VBAT_PIN        4       // T-Display S3 battery ADC (onboard 2x100k divider)
#define VBAT_LOW_MV     3400    // Low battery threshold in millivolts
#define VBAT_CUTOFF_MV  3100    // Software cutoff, deep sleep below this
#define VBAT_CUTOFF_COUNT 5     // Consecutive low reads required before cutoff
#define MENU_TIMEOUT_MS    6000
#define LONG_PRESS_MS      3000
#define MAX_CONSECUTIVE_ERRORS  60
#define WIFI_RETRY_WINDOW_MS    10000
#define WIFI_CHECK_INTERVAL_MS  30000
#define PIN_TIMEOUT_MS          15000
#define PIN_WRONG_MS            1500
#define LOWBAT_BLINK_MS         700
#define HEAP_LOG_MS             300000
#define BAT_READ_INTERVAL_MS    30000
#define ERROR_RETRY_MS          10000
#define SHELLY_OFFLINE_RETRY_MS 10000
#define CHARGE_RISE_MV          15
#define CHARGE_RISE_SAMPLES     3
#define BTN_ICON_X         294

// Blink API
#define BLINK_GRAPHQL_URL "https://api.blink.sv/graphql"

// Display (T-Display S3 landscape)
#define SCREEN_W 320
#define SCREEN_H 170

// QR code
#define QR_VERSION 10  // Max fallback; actual version chosen per data length (v3-v9). Covers LNURL ~115 chars (BTCPay) and BOLT11 ~257 chars (Blink).
                      
// Colors
#define COLOR_BG       TFT_BLACK
#define COLOR_TEXT     TFT_WHITE
#define COLOR_ACCENT   0xFD20    // Bitcoin orange
#define COLOR_SUCCESS  0x07E0    // Green
#define COLOR_ERROR    0xF800    // Red
#define COLOR_QR_FG    TFT_BLACK
#define COLOR_QR_BG    TFT_WHITE
#define COLOR_GRAY     0x7BEF

// Backend selection
enum BackendType {
  BACKEND_BTCPAY = 0,
  BACKEND_BLINK  = 1,
  BACKEND_COUNT // Sentinel: keep last for NVS validation
};

// Config struct
struct PlugNSatConfig {
  String wifiSsid;
  String wifiPass;
  String btcpayUrl;        // Instance URL, e.g. https://btcpay.mydomain.com
  String btcpayApiKey;
  String btcpayStoreId;
  String blinkApiKey;       // Blink API key (starts with blink_)
  String blinkWalletId;     // Blink BTC wallet ID
  String shellyHost;        // IP address or mDNS hostname, e.g. 192.168.1.42 or shellyplugsg3-xxxxxxxxxxxx.local
  int priceSats;           // Price per activation
  int activationDuration;  // Seconds relay stays ON after payment
  String deviceName;       // Shown on screen
  int brightness;          // Screen brightness (10-255)
  String pin;              // 4-digit PIN to protect Price/Duration (empty = disabled)
  bool showName;           // Show device name on QR screen
  bool showPrice;          // Show price on QR screen
  BackendType backendType; // Lightning backend (default: BTCPay)
  String portalPassword;   // HTTP Basic Auth for web portal (empty = no auth)
  bool autoUpdate;         // Check GitHub and auto-install on boot (default: false)
  bool isBattery;          // true = modele batterie, false = modele USB-C
  bool allowSelfSignedTls; // accepter un certificat auto-signe pour BTCPay (defaut false)
};

#endif

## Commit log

2026-03-28 feat: LNURL QR mode with dynamic sizing, BTCPay BTC-LN fix, brightness control, qrcode lib. Add file headers with license and references
    [config.h, display.h, plugnsat.ino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]
2026-03-28 fix: update webportal input placeholders with clearer examples, bump version to v0.1.0
    [webportal.h]
2026-03-28 fix: increase splash screen duration, update version number on display
    [display.h, plugnsat.ino]
2026-03-29 feat: add simulate payment button in device settings to test Shelly activation with configured duration
2026-04-15 feat: add mDNS Shelly autodiscovery with scan button in web portal
2026-04-15 fix: correct ESPmDNS API calls (queryService 2 args, address() not IP())
    [webportal.h]
2026-04-15 fix: move MDNS.begin() before web portal setup to ensure mDNS is initialized for Shelly scan
    [plugnsat.ino]
2026-04-15 fix: case-insensitive mDNS hostname filtering for Shelly device scan
    [webportal.h]
2026-04-15 feat: add Settings menu with Device Info and Brightness screen, persist brightness to NVS
2026-04-15 docs: update README with Settings menu, button mapping and brightness screen
2026-04-15 fix: detect button press on release instead of press to avoid long press conflicts
    [plugnsat.ino]
2026-04-22 fix: remove hardcoded brightness reset in displayQR and clean up unused button debounce globals
    [display.h, plugnsat.ino]
2026-04-22 feat: add back-to-WiFi button in AP mode with 3s guard and setup hint when unconfigured
2026-04-22 feat: replace splash screen with custom pixel art neon logo and add Price/Duration settings screens
    [display.h, plugnsat.ino]
2026-04-24 fix: center splash screen vertically and increase spacing before version badge
    [display.h]
2026-04-24 feat: add 4-digit PIN protection for Price and Duration settings, configurable via web portal
2026-05-06 feat: show padlock icon on PIN-protected settings menu items
2026-05-07 fix: increase text sizes and fix centering on paid screen
    [display.h]
2026-05-07 feat: redesign error screen with icon, live IP, countdown and max brightness
    [display.h, plugnsat.ino]
2026-05-07 feat: redesign info screen with colored header, network/session sections and metrics grid
    [display.h, plugnsat.ino]
2026-05-07 feat: redesign info screen loop/exit and add WiFi signal bars with RSSI thresholds
    [display.h, plugnsat.ino]
2026-05-07 fix: apply pixel gap to lightning bolt so it matches the PLUG/SAT pixel art style
    [display.h]
2026-05-07 feat: add enclosure STL files for the PlugNSat T-Display S3 case
    [plugnsat-case-bottom.stl, plugnsat-case-top.stl]
2026-05-07 docs: add enclosure README
    Added detailed information about the 3D printed case for the LilyGO T-Display S3, including print settings, files, and planned variants.
2026-05-07 fix: rename enclosure README to .md
2026-05-08 feat: redesign settings screen with taller buttons, centered layout, and cyan nav indicators
    [display.h]
2026-05-09 feat: update PIN entry screen with centered digit boxes, cyan nav indicators, and no button labels
2026-05-09 fix: increase spacing between padlock icon and label in settings for Price and Duration items
    [display.h]
2026-05-09 docs: update README with full setup flow and settings menu
2026-05-10 feat: redesign AP mode screen with gold rounded boxes, centered step layout, and white reconnect label
    [display.h]
2026-05-10 feat: redesign web portal with clean light theme
    [webportal.h]
2026-05-11 feat: replace text logo with inline pixel-art SVG matching tDisplay splash screen
    [webportal.h]
2026-05-11 fix: center price and duration values, remove split layout, replace button labels with cyan +/- icons matching settings screen
    [display.h]
2026-05-11 fix: center price/duration values full-screen, replace button labels with cyan +/- icons, fix brightness screen layout with centered bar and matching icon style
    [display.h]
2026-05-11 feat: polish display screens with consistent orange/cyan theming across settings, AP mode, device info, price and duration screens
2026-05-11 feat: add info tooltips to Shelly, buttons side-by-side with success/error feedback, switch all field focus color to cyan
    [webportal.h]
2026-05-11 feat: replace save confirmation with branded page showing pixel-art logo, recap card, and 3s countdown
    [webportal.h]
2026-05-11 feat: add show name/price toggles to webportal with info panel on QR screen (mini pixel-art logo, word-wrapped device name, price in sats)
2026-05-12 fix: improve info tooltip alignment and size
    [webportal.h]
2026-05-12 fix: shift QR code 7px right on info panel screen for better visual balance
    [display.h]
2026-05-12 fix: rename save page link to "Back to PlugNSat settings"
    [webportal.h]
2026-05-12 feat: add real-time device name validation tied to show-name toggle with 9-char/line TFT split
2026-05-12 feat: redesign paid screen with split layout, double green rings, larger amount, and clean countdown
    [display.h, plugnsat.ino]
2026-05-13 feat: add Shelly offline screen with split layout and remove legacy Shelly error overlay
    [display.h, plugnsat.ino]
2026-05-13 feat: redesign Shelly offline screen with centered layout, retry loop, and press-to-exit
    [display.h, plugnsat.ino]
2026-05-13 refactor: replace all BOLT11 with LNURL-only flow and redesign BTCPay error screen
    [display.h, plugnsat.ino]
2026-05-14 fix: restore BTC-LN payment method and split server error label to two lines
    [display.h]
2026-05-14 feat: redesign WiFi failed screen with split layout, signal bars, and settings-style button indicators
    [display.h, plugnsat.ino]
2026-05-14 chore: remove WiFi error screen test from startup
    [plugnsat.ino]
2026-05-15 refactor: move font and bolt bitmaps to file scope to eliminate duplication
2026-05-15 refactor: replace magic numbers with named constants for backlight pin, menu timeout, long press, and button icon position
    [config.h, display.h, plugnsat.ino]
2026-05-15 refactor: make loopPaid non-blocking using millis-based timer pattern
2026-05-15 refactor: replace recursive retry in generateAndShowQR with a for loop
    [plugnsat.ino]
2026-05-16 fix: mask WiFi password and settings PIN in web portal, preserving values on save if unchanged
    [webportal.h]
2026-05-16 fix: add htmlEscape() helper and sanitize all user-controlled config values in HTML templates to prevent stored XSS
    [webportal.h]
2026-05-17 fix: restore screen brightness before transitioning from PAID to SHELLY_OFFLINE state
    [plugnsat.ino]
2026-05-17 feat: log free heap every 5 minutes in loopQRDisplay to detect memory leaks during long operation
    [plugnsat.ino]
2026-05-18 fix: raise auto-restart threshold to 60 consecutive errors and check current invoice before replacing it to avoid missing a payment during QR refresh
    [plugnsat.ino]
2026-05-18 feat: add hardware watchdog timer (30s timeout) using ESP-IDF v5.x API to recover from any blocking hang in the main loop
2026-05-18 fix: correct typo in config.h header comment
    [config.h]
2026-05-18 docs: update README to reflect current behavior and recent changes
2026-05-19 fix: retry Shelly activation with full duration when it comes back online after an offline payment
    [plugnsat.ino]
2026-05-19 fix: move watchdog init from setup() to first loop() iteration to prevent false reboot during WiFi connection and splash screen
    [plugnsat.ino]
2026-05-19 fix: when Shelly comes back online after offline payment, show full PAID screen with countdown instead of jumping directly to new QR
    [plugnsat.ino]
2026-05-19 fix: protect /api/status endpoint with portal authentication
    [webportal.h]
2026-05-19 fix: validate host parameter in /test-shelly to block URL injection attempts
    [webportal.h]
2026-05-19 fix: add upper bound validation on all config fields in /save handler to prevent oversized input
    [webportal.h]
2026-05-19 fix: reset lastDisplayedSecond on all exits of loopError to prevent stale screen state
    [plugnsat.ino]
2026-05-19 docs: update Shelly offline edge case in README to reflect actual retry and activation behavior
2026-05-25 refactor: rename currentLnurl to currentQRData for backend-neutral naming and clear it alongside currentInvoiceId in loopShellyOffline
2026-05-25 feat: add Blink NVS persistence, widen CheckInvoiceFn to accept invoicePayload for BOLT11 status checks
2026-05-25 feat: wire Blink into backend.h replacing stubs with real wrappers calling blink.h
2026-05-25 fix: add QR version 9 tier to renderQR() so BOLT11 strings up to 335 chars render at 3px/module instead of 2, extracted into shared qrVersionForLength()
    [display.h]
2026-05-25 fix: (webportal) merge backend selector and settings into single card
    [webportal.h]
2026-05-26 fix: clear currentInvoiceId and currentQRData before generateAndShowQR() in loopPaid() to prevent infinite paid/activation loop
    [plugnsat.ino]
2026-05-26 feat: add descriptive memo to Blink invoices showing device name and amount
2026-05-26 docs: rewrite all remaining portal tooltip texts to be shorter and more user-friendly
    [webportal.h]
2026-05-26 refactor: rename Security fields to Device PIN and Web Access Password, rewrite their tooltips and hints, and remove portal wording from all user-visible text
2026-05-29 feat: redesign enclosure bottom with wall/mount screw holes, rear magnet cutout, and updated ventilation pattern
    [plugnsat-case-bottom.stl, plugnsat-case_bottom.stl]
2026-06-03 docs: add "Power on the PlugNSat" section with boot screen screenshots
2026-06-05 docs: restructure roadmap for battery-first launch, defer NFC to post-v1.0
2026-06-08 feat: add dual-slot partition table and app validity mark for rollback support
    [partitions_ota.csv]
2026-06-08 docs: add Arduino IDE partition scheme setup note in plugnsat.ino
2026-06-08 fix: replace esp_ota_get_state_info with esp_ota_get_state_partition
    [ota.h]
2026-06-08 feat: add processOtaPage helper to render OTA page with version and device name
2026-06-08 feat: replace text logo with SVG logo and match main page header style on OTA page
    [webportal.h]
2026-06-09 fix: move ota.h include before webportal.h to resolve otaVerifySignature forward declaration
    [plugnsat.ino]
2026-06-09 feat: add Check for updates button to OTA page with GitHub release comparison
2026-06-10 feat: add Install update button and one-click auto-flash flow from GitHub Releases
2026-06-10 fix: add missing Update.h include in ota.h
    [ota.h]
2026-06-11 fix: stream firmware to flash in chunks to avoid heap exhaustion during OTA update
    [webportal.h]
2026-06-11 feat: add opt-in auto-update on boot with silent fallback on failure
    [plugnsat.ino]
2026-06-11 fix: compare firmware versions with semver ordering to prevent update boot loop
    [ota.h]
2026-06-11 chore: remove custom partition table and update OTA setup note
    [partitions_ota.csv]
2026-06-11 fix: add type="button" to btn-install and clean up portal update JS
    [webportal.h]
2026-06-11 fix: treat GitHub 404 as up-to-date instead of an error in otaCheckUpdate
    [ota.h]
2026-06-12 docs: add user manual with overview and button reference
2026-06-12 docs: add settings menu section with device info, brightness, and price screens
2026-06-12 fix: regenerate invoice when price changed via device menu
    [plugnsat.ino]
2026-06-12 docs: add duration and PIN entry screens to settings menu section
2026-06-15 fix: drive GPIO15 high on boot to power the screen on battery
    [plugnsat.ino]
2026-06-15 feat: add isBattery flag to config struct to distinguish USB-C and battery models
2026-06-15 feat: add battery model toggle to web portal device settings
2026-06-15 feat: add battery voltage reading with ADC calibration factor
2026-06-15 feat: show battery gauge on device info screen for battery model
2026-06-15 fix: discard first ADC reading on boot to avoid unstable VBAT value
    [plugnsat.ino]
2026-06-15 fix: shift version label right to avoid overlap with logo on battery info screen
    [display.h]
2026-06-15 feat: add drawLowBatteryWarning icon for low battery overlay on main screen
2026-06-15 feat: blink low battery warning icon on QR screen for battery model
2026-06-15 feat: add charging icon to device info battery gauge when fully charged
2026-06-15 feat: detect charging state by voltage trend and show charging icon in device info
2026-06-15 feat: add software low-voltage cutoff with deep sleep for battery model
2026-06-15 feat: add manual power off (manual deep sleep) option to settings menu for battery model only
2026-06-15 feat: show Turn OFF entry in settings menu for battery model
2026-06-15 fix: enable RTC pull-up on BTN_1 before deep sleep to prevent immediate wake
    [plugnsat.ino]
2026-06-16 fix: recalibrate LiPo percent curve to match real 3100-4200mV discharge range
    [display.h]
2026-06-16 fix: hold GPIO15 low during deep sleep to cut screen power rail consumption
    [plugnsat.ino]
2026-06-16 fix: require 3 consecutive rising readings before setting isCharging to avoid rebound false positive
    [plugnsat.ino]
2026-06-16 feat: reorder battery gauge to percent, icon, voltage with level-colored percent
2026-06-16 feat: replace battery model toggle with USB-C/Battery segmented control in device settings
    [webportal.h]
2026-06-16 docs: fix coherence issues across README, quick-start and user-manual for battery model and settings menu
2026-06-16 docs: add battery gauge entry to device info screen description
2026-06-17 fix: recalibrate battery percent curve on measured full discharge test
    [display.h]
2026-06-18 docs: add Shelly, device settings, security, firmware and after-saving sections to web portal reference
2026-06-18 fix: align Arduino board name to ESP32S3 Dev Module in plugnsat.ino header comment
    [plugnsat.ino]
2026-06-18 fix: enforce authentication on OTA upload endpoint
    [webportal.h]
2026-06-18 fix: add OTA firmware size cap to reject uploads exceeding 1.9 MB
    [ota.h, webportal.h]
2026-06-18 fix: harden /test-shelly host validation and add OTA upload size cap
    [webportal.h]
2026-06-19 fix: fire BTN1 long-press AP mode action only once per press
    [plugnsat.ino]
2026-06-19 fix: add yield and early exit to OTA signature read loop
    [ota.h]
2026-06-21 refactor: replace color565 recalculations with COLOR_ORANGE_D/CYAN_D/YELLOW_D constants
    [display.h]
